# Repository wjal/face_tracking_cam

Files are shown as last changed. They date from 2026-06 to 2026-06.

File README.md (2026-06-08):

# Face-Tracking Pan/Tilt Camera System







A real-time, closed-loop face-tracking system that uses computer vision to detect a face and physically reorients a camera to keep it centered. A Raspberry Pi 5 performs frame capture and face detection, streams bounding-box coordinates over UART to an Arduino, which drives two servos mounted in a custom 3D-printed pan/tilt gimbal arm.

---

## Table of Contents

- [System Overview](#system-overview)
- [Hardware](#hardware)
- [Software Stack](#software-stack)
- [How It Works](#how-it-works)
- [UART Communication Protocol](#uart-communication-protocol)
- [Servo Control Logic](#servo-control-logic)
- [Project Structure](#project-structure)
- [Setup & Installation](#setup--installation)
- [Usage](#usage)
- [Roadmap](#roadmap)

---

## System Overview

```
┌──────────────────────────────────────┐    UART 9600 baud    ┌───────────────────────────────┐
│           Raspberry Pi 5             │  ─────────────────►  │            Arduino            │
│                                      │                      │                               │
│  ┌────────────┐    ┌───────────────┐ │  5-byte packet:      │  ┌──────────┐  ┌───────────┐  │
│  │  Pi Camera │──► │ OpenCV Haar   │ │  [0xFF]              │  │  Pan     │  │   Tilt    │  │
│  │  (CSI)     │    │ Face Detect   │ │  [X_lo][X_hi]        │  │  Servo   │  │   Servo   │  │
│  └────────────┘    └──────┬────────┘ │  [Y_lo][Y_hi]        │  └────┬─────┘  └─────┬─────┘  │
│                           │          │                      │       │               │        │
│                    BBox center (x,y) │                      └───────┼───────────────┼────────┘
│                                      │                              │               │
└──────────────────────────────────────┘                             ▼               ▼
                                                          ┌──────────────────────────────────┐
                                                          │  Custom 3D-Printed Pan/Tilt Arm  │
                                                          │  (2-joint gimbal-style mechanism) │
                                                          └──────────────────────────────────┘
```

The system forms a continuous closed-loop: the camera sees the face, the Pi computes the error from center, the Arduino corrects the servo angles, and the gimbal repositions the camera. Repeat.

---

## Hardware

| Component | Details |
|---|---|
| SBC | Raspberry Pi 5 |
| Camera | Raspberry Pi Camera Module (CSI interface) |
| Microcontroller | Arduino (Uno / Nano) |
| Servo – Pan | Standard RC hobby servo → pin D9 |
| Servo – Tilt | Standard RC hobby servo → pin D10 |
| Gimbal Mechanism | Custom 3D-printed pan/tilt arm (see below) |
| Level Converter | Custom-built 3.3 V → 5 V shifter using 2N7000 N-channel MOSFET (see below) |
| Pi ↔ Arduino Link | UART via GPIO 14/15 (TX/RX) → level converter → Arduino D0/D1 |

### Custom Pan/Tilt Gimbal

The camera mount is a custom-designed and 3D-printed two-joint arm. Each joint is driven by one servo, providing a pan axis (horizontal) and a tilt axis (vertical). The assembly functions as a gimbal, giving the camera roughly 180° of range on each axis. The geometry was designed around the servo horn attachment points to minimize backlash and distribute load evenly across the printed structure.

### Custom Logic-Level Converter

Rather than using an off-the-shelf level-shifter module, a discrete converter was designed and built around the **2N7000 N-channel enhancement-mode MOSFET** (TO-92 package). The circuit translates the Raspberry Pi's 3.3 V UART TX signal to a 5 V-compatible level for the Arduino's serial RX input, preventing any risk of back-driving the Pi's GPIO and ensuring clean signal levels across the voltage domain boundary.

The 2N7000 was chosen for its low threshold voltage (V<sub>GS(th)</sub> ≈ 0.8 – 3 V), making it reliably switchable by a 3.3 V gate signal, and its small TO-92 footprint. A schematic and bill of materials will be added to the `hardware/` directory.

---

## Software Stack

### Raspberry Pi — Python 3

| Library | Purpose |
|---|---|
| `picamera2` | Native Raspberry Pi Camera Module interface |
| `opencv-python` | Haar Cascade face detection, frame annotation |
| `pyserial` | UART serial communication |
| `numpy` | Frame array manipulation |
| `struct` | Binary packet packing for UART transmission |

### Arduino — C++

| Library | Purpose |
|---|---|
| `Servo.h` (built-in) | PWM servo angle control |
| `Serial` (built-in) | Hardware UART receive and debug output |

---

## How It Works

1. **Frame Capture** — `Picamera2` captures a `720 × 680` BGR frame at up to 30 fps over the CSI interface.
2. **Grayscale Conversion** — The frame is converted to grayscale to reduce the computational load on the Haar cascade.
3. **Face Detection** — OpenCV's Haar Cascade classifier (`haarcascade_frontalface_default.xml`) scans the frame. When multiple faces are detected, the first result is tracked.
4. **Center Calculation** — The center pixel of the face bounding box is computed as `(x + w/2, y + h/2)`.
5. **UART Transmission** — A 5-byte little-endian binary packet is packed with `struct` and transmitted over `/dev/serial0` to the Arduino.
6. **Error Computation** — The Arduino calculates the offset of the face center from the frame midpoint `(360, 340)`.
7. **Servo Correction** — A proportional controller (with dead zone) computes angular deltas for each axis and drives the servos accordingly.
8. **Performance Monitoring** — An exponential moving average (α = 0.1) tracks loop time and displays a live FPS estimate on the preview window.
9. **Video Recording** — The annotated output is simultaneously written to `face_track_proto.mp4` via OpenCV's `VideoWriter`.

---

## UART Communication Protocol

Each message is a fixed **5-byte little-endian binary packet**:

```
 Byte 0    Byte 1    Byte 2    Byte 3    Byte 4
┌────────┬──────────┬──────────┬──────────┬──────────┐
│  0xFF  │  X_low   │  X_high  │  Y_low   │  Y_high  │
└────────┴──────────┴──────────┴──────────┴──────────┘
  Start    ◄─── X center coord (uint16, LE) ───►   ◄─── Y center coord (uint16, LE) ───►
```

| Field | Type | Range | Description |
|---|---|---|---|
| `0xFF` | `uint8` | — | Frame sync / start byte |
| `X` | `uint16` little-endian | 0 – 720 | Horizontal pixel of face bounding box center |
| `Y` | `uint16` little-endian | 0 – 680 | Vertical pixel of face bounding box center |

> ⚠️ **Sync Note:** The frame dimensions (`FRAME_WIDTH = 720`, `FRAME_HEIGHT = 680`) are hardcoded on both sides. If the camera resolution is changed in `main.py`, the matching `#define` values in the Arduino sketch must also be updated.

**Raspberry Pi — packing:**
```python
ser.write(struct.pack('<BHH', 0xFF, int(x + w/2), int(y + h/2)))
```

**Arduino — unpacking:**
```cpp
uint8_t xLow  = Serial.read();
uint8_t xHigh = Serial.read();
uint8_t yLow  = Serial.read();
uint8_t yHigh = Serial.read();

x_coord = xLow  | (xHigh << 8);
y_coord = yLow  | (yHigh << 8);
```

---

## Servo Control Logic

The Arduino implements a **proportional controller with a dead zone** to prevent jitter when the face is already near-centered.

```
Frame center:  x_mid = 360,  y_mid = 340
Dead zone:     ± 35 pixels on each axis

Pan axis (horizontal):
  if |x_coord - x_mid| > 35:
      pan_move        = ((x_coord - x_mid) / x_mid) × 12 + 1
      pan_angle      -= pan_move          ← sign inverted for physical orientation

Tilt axis (vertical):
  if |y_coord - y_mid| > 35:
      tilt_move       = ((y_coord - y_mid) / y_mid) × 12 + 1
      tilt_angle     += tilt_move

Both axes clamped to [0°, 180°]
```

| Parameter | Value |
|---|---|
| Home position — Pan | 110° |
| Home position — Tilt | 10° |
| Max angular step per frame | ~13° |
| Servo range | 0° – 180° |
| Dead zone radius | ± 35 px |

The proportional gain (`12`) and dead zone (`35 px`) are empirically tuned constants. A PID controller is planned as a future improvement to reduce overshoot and oscillation.

---

## Project Structure

```
face_tracking/
├── hardware/
│   ├── CAM_SERVOS.stl                           # 3D-printable pan/tilt gimbal arm
│   └── level_converter (TODO)                   # 2N7000 logic-level converter schematic (TBD)
├── arduino/
│   └── src/
│       └── main.cpp                             # Arduino: UART RX, proportional servo control
├── pi/
│   ├── main                                     # Pi: frame capture, face detection, UART TX
│   └── data/
│       ├── haarcascade_frontalface_default.xml  # Haar face cascade model
│       └── haarcascade_eye.xml                  # Haar eye cascade (present, not yet active)
└── README.md
```

---

## Setup & Installation

### Raspberry Pi

#### 1. Enable UART and disable serial console

```bash
sudo raspi-config
# Navigate to: Interface Options → Serial Port
#   "Login shell accessible over serial?" → No
#   "Serial port hardware enabled?"       → Yes
```

Or manually in `/boot/firmware/config.txt`:
```
enable_uart=1
```

Reboot after making changes.

#### 2. Install Python dependencies

```bash
pip install picamera2 opencv-python pyserial numpy
```

#### 3. Add Haar cascade model files

Copy the two XML files into the `data/` directory. They ship with OpenCV and can be located with:

```bash
find / -name "haarcascade_frontalface_default.xml" 2>/dev/null
```

#### 4. Wire UART through the level converter

The Pi's 3.3 V TX line passes through the custom 2N7000 level-converter circuit before reaching the Arduino's 5 V RX pin.

| Signal path | Connection |
|---|---|
| Pi GPIO 14 (TX, 3.3 V) | → Level converter input |
| Level converter output (5 V) | → Arduino D0 (RX) |
| Pi GPIO 15 (RX) | → Arduino D1 (TX) *(currently unused — Pi only transmits)* |
| Pi GND | → Level converter GND → Arduino GND |

> See `hardware/` for the level converter schematic and BOM.

---

### Arduino

1. Open `arduino/servo_controller/main.cpp` in Arduino IDE or PlatformIO.
2. Connect servos:
   - Pan servo signal wire → **D9**
   - Tilt servo signal wire → **D10**
   - Both servo power/ground to an appropriate 5 V supply (not the Arduino's 5 V pin for two servos under load).
3. Compile and upload to the board.
4. Open the Serial Monitor at **9600 baud** to confirm `"Setup complete."` and verify live `pan angle` / `tilt` debug output.

---

## Usage

```bash
# On the Raspberry Pi
python3 main.py
```

- A live preview window labeled **"Camera"** opens showing the annotated color frame.
- A second window labeled **"FRAME"** shows the grayscale feed used for detection.
- A green bounding box is drawn around the first detected face.
- FPS and loop time are overlaid in the top-left corner.
- Press **`q`** in either preview window to exit cleanly.
- Output video is saved to `face_track_proto.mp4` in the working directory on exit.

> The script handles `KeyboardInterrupt` (Ctrl+C) gracefully, ensuring the serial port, VideoWriter, and camera are all properly released.

---

## Roadmap

- [ ] Arduino: replace polling loop with interrupt-driven serial handling and a cooperative task manager
- [ ] Replace proportional controller with a full **PID controller** to reduce overshoot and settling time
- [ ] Add multi-face selection logic (largest bounding box, or nearest to previous position)
- [ ] Re-enable and tune **eye detection** within the face ROI for sub-region tracking
- [ ] Tune dead zone and proportional gain constants with systematic testing
- [ ] Evaluate switching to a DNN-based face detector (`cv.dnn`) for improved accuracy and lighting robustness
- [ ] Gimbal v2: refined 3D-printed geometry for reduced backlash and cleaner cable routing

---

*Built as a personal embedded systems and computer vision project — integrating real-time image processing, custom firmware, binary UART protocol design, discrete circuit design (custom logic-level converter), and 3D-printed mechanical design into a single closed-loop tracking system.*

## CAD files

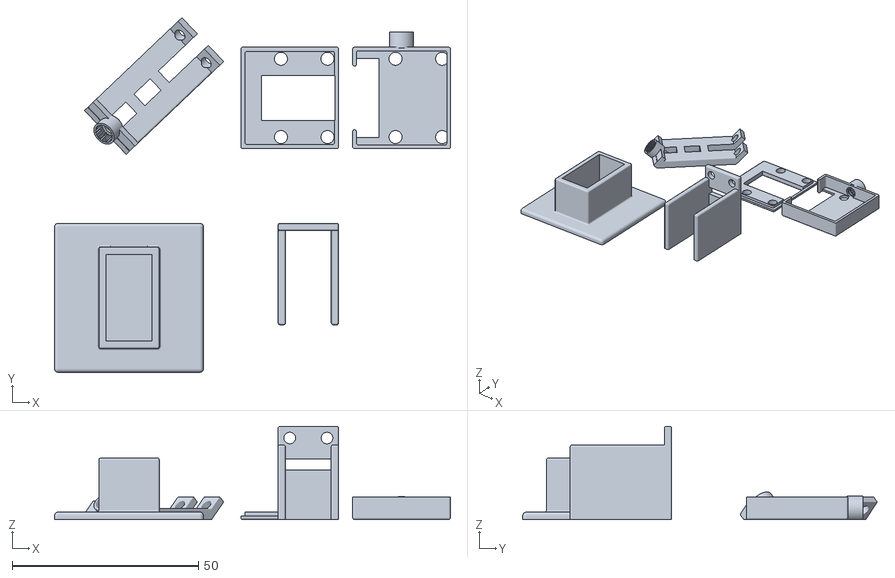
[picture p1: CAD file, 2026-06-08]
hardware/CAM_SERVOS.stl
106.2 x 95.2 x 25.0

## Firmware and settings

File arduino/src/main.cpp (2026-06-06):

#include <Arduino.h>
#include <Servo.h>
// put function declarations here:
#define SERVO_MAX       180
#define SERVO_MIN       0
#define pan_servo_pin   9
#define tilt_servo_pin  10
#define FRAME_WIDTH     720
#define FRAME_HEIGHT    680
#define X_ANGLE_START   110
#define Y_ANGLE_START   10
  // put your main code here, to run repeatedly:
char incomingByte = 0; // for incoming serial data
char dump = 0;
uint16_t x_coord = 0;
uint16_t y_coord = 0;
char g_buff[128];

uint16_t x_mid = FRAME_WIDTH/2;
uint16_t y_mid = FRAME_HEIGHT/2;
int16_t pan_servo_angle = X_ANGLE_START;
int16_t tilt_servo_angle = Y_ANGLE_START;
int16_t tilt_move = 0;
int16_t pan_move = 0;

Servo tilt_servo;
Servo pan_servo;

void setup() {
  Serial.begin(9600); // opens serial port, sets data rate to 9600 bps
  Serial.println("Setting up....");
  pan_servo.attach(pan_servo_pin);
  tilt_servo.attach(tilt_servo_pin);
  pan_servo.write(X_ANGLE_START);
  tilt_servo.write(Y_ANGLE_START);
  Serial.println("Setup complete.");
}

void loop() {
    if (Serial.available() >= 5) {
        if (Serial.read() == 0xFF) {
            uint8_t xLow = Serial.read();
            uint8_t xHigh = Serial.read();
            uint8_t yLow = Serial.read();
            uint8_t yHigh = Serial.read();
            
            x_coord = xLow | (xHigh << 8);
            y_coord = yLow | (yHigh << 8);
            

          if(x_coord > (x_mid + 35) || x_coord < (x_mid - 35)){
            pan_move = (int)(((float)((int16_t)x_coord - (int16_t)x_mid) / x_mid) * 12) + 1;
            pan_servo_angle-=pan_move;
            if(pan_servo_angle > SERVO_MAX){
              pan_servo_angle = SERVO_MAX;
            }else if(pan_servo_angle < SERVO_MIN){
              pan_servo_angle = SERVO_MIN;
            }
          }
            
          if(y_coord > (y_mid + 35) || y_coord < (y_mid - 35)){
            tilt_move = (int)(((float)((int16_t)y_coord - (int16_t)y_mid) / y_mid) * 12) + 1;
            tilt_servo_angle+=tilt_move;
            if(tilt_servo_angle > SERVO_MAX){
              tilt_servo_angle = SERVO_MAX;
            }else if(tilt_servo_angle < SERVO_MIN){
              tilt_servo_angle = SERVO_MIN;
            }
          }
          pan_servo.write(pan_servo_angle);
          tilt_servo.write(tilt_servo_angle);
          sprintf(g_buff, "pan angle: %d tilt: %d\n", pan_servo_angle, tilt_servo_angle);
          Serial.print(g_buff);
        }
    }
}

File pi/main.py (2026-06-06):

#!/usr/bin/env python3
import serial
import struct
import cv2 as cv
from picamera2 import Picamera2
import numpy as np
from datetime import datetime

width = 720
height = 680

# Initialize the serial port
# Use '/dev/serial0' as a universal alias across different Raspberry Pi models
ser = serial.Serial(
    port='/dev/serial0',
    baudrate=9600,
    parity=serial.PARITY_NONE,
    stopbits=serial.STOPBITS_ONE,
    bytesize=serial.EIGHTBITS,
    timeout=1
)


position=(30,40)
font=cv.FONT_HERSHEY_PLAIN
text_height=1.5
colour=(0,242,5)
weight=2
line=cv.LINE_AA
rec_colour=(20,30,200)
box_thickness=7

#center pixel
pixel_x = int(width/2)
pixel_y = int(height/2)


picam2 = Picamera2()
picam2.configure(picam2.create_preview_configuration(main={"size":(width,height), "format": "BGR888"},controls={"FrameRate":30}))
picam2.start()

frame = picam2.capture_array()
frame_height, frame_width = frame.shape[:2]  # numpy shape is (height, width, channels)
out_mp4 = cv.VideoWriter("face_track_proto.mp4", cv.VideoWriter_fourcc(*"mp4v"), 10, (frame_width, frame_height))

box_height = 1
box_width = 1
x_pos=1
y_pos=1

#used temp
x = 90
y = 90

face_cascade = cv.CascadeClassifier('./data/haarcascade_frontalface_default.xml')
eye_cascade = cv.CascadeClassifier('./data/haarcascade_eye.xml')

resize_dimensions = (int(width/4),int(height/4))
total=1
calc=1
try:
    while True:
        start = datetime.now()
        frame = picam2.capture_array()
        frame_gray = cv.cvtColor(frame, cv.COLOR_BGR2GRAY)
        #frame_gray = cv.resize(frame_gray_pre, resize_dimensions)
        faces = face_cascade.detectMultiScale(frame_gray, 1.3, 5)
        

        calc = (.9 * calc) + (0.1 * (1.0 / total))
        text = f"fps={int(calc)} loop_time={total}"
        cv.imshow('FRAME', frame_gray)
        cv.putText(frame, text, position, font, text_height, colour, weight, line)
        if cv.waitKey(1) == ord('q'):
            break
        #for face in faces:
        if len(faces) > 0:
            x,y,w,h=faces[0]
            cv.rectangle(frame, (x,y), (x+w, y+h),(0,0,255),3)
            message = ser.write(struct.pack('<BHH', 0xFF,  int((x)+(w/2)), int((y)+(h/2))))
            roi_gray = frame_gray[y:y+h,x:x+w]
            eyes = eye_cascade.detectMultiScale(roi_gray, 2.25, 25)

            #for eye in eyes:
                #### these lines need to be rechecked
                #e_x,e_y,e_w,e_h=eye
                #these lines need to be checked
                #cv.rectangle(frame, (e_x+x,e_y+y), (x+e_x+e_w, y+e_y+e_h),(0,0,255),3)
        cv.imshow("Camera", frame)
        out_mp4.write(frame)
        total = (datetime.now() - start).total_seconds()
except KeyboardInterrupt:
    pass
finally:
    ser.close() # Always close the port when finished
    cv.destroyAllWindows()
    out_mp4.release()
    picam2.stop()
    print("\nExiting Program")

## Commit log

2026-06-06 added hardware directory - partial stl parked
    [CAM_SERVOS.stl]
2026-06-08 updated stl
    [CAM_SERVOS.stl]
